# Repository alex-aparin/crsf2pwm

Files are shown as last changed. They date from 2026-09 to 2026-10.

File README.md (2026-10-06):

# crsf2pwm




CRSF-to-PWM converter for an RC car: receives CRSF from an ExpressLRS or
Crossfire receiver over UART and outputs two servo PWM signals, one for the
steering servo and one for the motor ESC. Plain synthesisable
SystemVerilog, one clock, no vendor primitives. The current target is a
Cyclone IV E development board; a MAX II EPM240 revision exists but the
design is a few logic cells too big for it.

## Layout

```
rtl/          synthesizable code, the only thing that goes into Quartus
tb/           testbenches for Icarus Verilog, one per module plus tb_top
tb/lib/       helpers shared by the testbenches (CRC, frame building)
tb/model/     Python reference model and the test vector generator
tb/vectors/   generated vectors, committed, `make vectors` regenerates them
sim/          Makefile for running simulations, waveforms land here
quartus/      Quartus project: .qpf, one .qsf per revision, .sdc, the clock probe
tools/        build, JTAG check, program, udev rule for the USB Blaster
hw/           KiCad board project
docs/         notes: design, CRSF protocol, servo PWM, pinout, board bring-up
```

## Design

```
rx -> 2 FF sync -> uart_rx -> crsf_parser -> steer_val ----------> pwm_chan -> steer
                                          -> thr_val -> failsafe mux -> pwm_chan -> throttle
                                          -> frame_valid -> link watchdog
                              pwm_timebase -> tick, start, head -> both channels, watchdog
```

`docs/design.md` has the module contracts, the timing, the failsafe policy,
the LE budget and the reasoning behind the choices. `docs/crsf.md` and
`docs/servo_pwm.md` cover the two protocols.

## Tools (Linux)

Simulation and lint from the distribution:

```
sudo apt install iverilog gtkwave make python3 verilator
```

Quartus Prime Lite for synthesis and programming: the small installer from
altera.com (`qinst-lite-linux-<version>.run`, free, needs an account),
components Quartus Prime plus the Cyclone IV device support, and MAX II if
the CPLD revision matters; Questa is not needed. It lands in
`~/altera_lite/<version>/quartus`, which is not on PATH: the scripts in
`tools/` find it by themselves, and `. tools/quartus-env.sh` puts it on
PATH for a shell. The USB Blaster needs `tools/udev-install.sh` once.

Verified with Icarus 11, Verilator 5.052, Quartus Prime Lite 25.1std on
Ubuntu 22.04.

## Simulation

Without make, from the `sim` directory:

```
mkdir build
iverilog -g2012 -Wall -I ../tb/lib -s tb_top -o build/tb_top.vvp ../tb/tb_top.sv ../rtl/*.sv
vvp -N build/tb_top.vvp
gtkwave build/tb_top.vcd
```

With make:

```
cd sim
make                 all testbenches
make tb_top          one testbench
make pwm_out         same as make tb_pwm_out
make waves-tb_top    open waveforms in GTKWave
make lint            Verilator lint, if installed
make vectors         regenerate tb/vectors from the Python model
```

Every testbench is self-checking: it prints `PASS` and exits 0, or prints the
failing checks and exits 1 through `$stop`, so `make` fails and the VS Code
task turns red. A watchdog ends a hung run.

`make waves-tb_top` also loads `sim/tb_top.gtkw` if it exists. Save one from
GTKWave with File > Write Save File to keep the signal layout between runs.

## Continuous integration

`.github/workflows/sim.yml` runs on every push and pull request: all
testbenches in Icarus (`make -C sim -k all`), the Python model self-test with
a check that the committed `tb/vectors/` match the generator, and Verilator
lint of the RTL with `-Wall`. The waveforms of a failed run are attached to
the run as an artifact for a week. The badge above shows the state of `main`.

`.github/workflows/hw.yml` runs on changes under `hw/`: ERC of the schematic
and DRC of the board with kicad-cli 10.0 (through `actions-for-kicad/kicad-actions`),
plus a PDF of the schematic and of the board layers. Reports and PDFs are
attached to the run as the `board` artifact for 30 days. ERC tolerates only
"Pin not connected" on the unused U1 pins, which have no no-connect flags yet.

## VS Code

`.vscode/` has tasks and recommended extensions. Open a testbench or a module
file and press Ctrl+Shift+B: the testbench for that file runs in `sim/`, so
`rtl/pwm_out.sv` and `tb/tb_pwm_out.sv` both run `tb_pwm_out`. Errors from
Icarus appear in the Problems panel. Other tasks under Terminal > Run Task:
waves in GTKWave, run + waves, all testbenches, lint, clean.

The Verilog-HDL extension lints the open file with Icarus on save. The Surfer
extension opens a `.vcd` from `sim/build/` inside VS Code as an alternative
to GTKWave.

## Build and program

The Quartus project `quartus/crsf2pwm.qpf` has three revisions:

| Revision | Target | Output |
|---|---|---|
| `crsf2pwm_c4` | the Saylinx Cyclone IV board, EP4CE6F17C8N | `.sof`, and `.jic` for the flash |
| `clock_probe` | the same board, bring-up helper: oscillator to LEDs and header pins | `.sof` |
| `crsf2pwm` | MAX II EPM240 | `.pof`; 234 of 240 LEs with the area settings in the `.qsf`, see `docs/design.md` |

Everything goes through the scripts in `tools/`, which find Quartus, check
the cable and print the numbers that matter:

```
tools/udev-install.sh            once: let Quartus open the USB Blaster
tools/jtag-check.sh              cable found? board answering?
tools/build.sh [revision]        compile, default crsf2pwm_c4; errors, warnings by code, LEs, slack
tools/program.sh [revision]      into the FPGA over JTAG, gone at power-off
tools/program.sh --flash         into the configuration flash, loads at every power-up
tools/crsf_send.py [options]     play a receiver: CRSF frames from the PC over the board's USB-UART (pyserial)
```

The step-by-step procedure with what to expect at each step, from the
first `jtagconfig` to the car, is `docs/bringup.md`. The GUI works too:
open the `.qpf`, pick the revision under Project > Revisions, Start
Compilation, Programmer.

Current state: the Cyclone IV revision compiles clean in Quartus Prime
Lite 25.1 (273 LEs, Fmax well above 50 MHz) with the pins from
`docs/pinout.md`. Not yet confirmed on the board.

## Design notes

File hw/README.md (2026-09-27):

# Board

KiCad project: `crsf2pwm-board.kicad_pro`, `.kicad_sch`, `.kicad_pcb`.

- `lib/` project symbols, footprints and 3D models, paths via `${KIPRJMOD}`.
- `fab/` gerbers, BOM and position file, committed at the moment of ordering boards.
- Net names as in `docs/pinout.md`.

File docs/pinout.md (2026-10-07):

# Pinout

Net names in KiCad match the ports of `crsf2pwm_top`. When changing a
pin, update three places: this table, the revision's `.qsf`
(`quartus/crsf2pwm_c4.qsf` for Cyclone IV, `quartus/crsf2pwm.qsf` for
MAX II), and the schematic.

Four pins in total. `clk` must sit on a dedicated clock input: GCLK0..3
(pins 12, 14, 62, 64) on the EPM240T100, CLK0..CLK15 on the Cyclone IV E;
the fitter warns when a clock is placed elsewhere. The other three go on
any user I/O that reaches a header and is not shared with an on-board LED,
button or memory.

Cyclone IV board: Saylinx, EP4CE6F17C8N (256-pin BGA, pins named like
E1), a clone of the ALINX AX4010. The basics-graphics-music project
(github.com/yuri-panchul/basics-graphics-music) has this exact board as
`boards/saylinx`: its `board_specific.qsf` lists every pin and matches the
silkscreen here, and `board_specific_top.sv` shows the polarities: keys
are active low, LEDs light on 1, 7-segment segments and digits are active
low.

| Net | Module port | Cyclone IV pin | EPM240 pin | Board connector | Notes |
|---|---|---|---|---|---|
| CLK50 | clk | E1 | 64 (GCLK3) | on-board oscillator | 50 MHz, dedicated clock input |
| CRSF_RX | rx | M2 | 54 + 55 | on-board USB-UART bridge, PC -> FPGA | frames from a PC over the board's mini-USB; for a receiver switch to T14 (right header pin 3, GND pin 1), 3.3 V, idle high, receiver RX pin left open |
| STEER | steer | T13 | 49 + 50 | right header pin 5 | servo powered separately, 220 ohm .. 1 k series resistor |
| THROTTLE | throttle | T12 | 51 + 52 | right header pin 7 | ESC powered separately, same resistor |
| LED0..3 | led[0..3] | D9, C9, F9, E10 | | on-board LEDs, light on 1 | status: link, frames, first frame, rx activity |

On the EPM240 each signal takes a pair of adjacent package pins. The port
sits on the first pin of the pair; the second is reserved in the `.qsf` as
a tri-stated input (`RESERVE_PIN`) and both pads are joined on the board,
so the pad is twice as wide and a solder bridge inside the pair changes
nothing. Pins 53, 56 and 57 stay free as spacers. In the same spirit pin 58
is tied to VCCIO2 (pin 59) and pin 61 to GNDIO (pin 60), both reserved as
tri-stated inputs: the one state that is safe against either rail, whatever
the global unused-pin setting becomes. The pairs straddle the I/O bank
boundary (51 is bank 1, 52 bank 2); both banks run at 3.3 V.

Other board resources, from the AX4010 data, for later: keys M15, M16,
E16 and reset N13 (with pull-ups); the on-board USB-UART bridge connects
to the FPGA on M2 (FPGA receives) and N1 (FPGA transmits), an option for
feeding test frames from the PC without a separate adapter.

## Saylinx board headers

Transcribed from the silkscreen on the bottom side; the labels are FPGA
pin names. "Left" and "right" are as seen from the bottom, with the VGA
connector at the top.

Left header, numbering starts at the top row, `[2] [1]`: even pins in the
left column, odd in the right.

| Pins | Left | Right |
|---|---|---|
| 2, 1 | VCC | GND |
| 4, 3 | J16 | B1 |
| 6, 5 | A2 | B3 |
| 8, 7 | A3 | B4 |
| 10, 9 | A4 | B5 |
| 12, 11 | A5 | B6 |
| 14, 13 | A6 | B7 |
| 16, 15 | A7 | B8 |
| 18, 17 | A8 | B9 |
| 20, 19 | A9 | B10 |
| 22, 21 | A10 | B11 |
| 24, 23 | A11 | B12 |
| 26, 25 | A12 | B13 |
| 28, 27 | A13 | D5 |
| 30, 29 | D6 | C6 |
| 32, 31 | E7 | F8 |
| 34, 33 | C8 | D8 |
| 36, 35 | E8 | E9 |
| 38, 37 | GND | GND |
| 40, 39 | 3V3 | 3V3 |

Right header, numbering starts at the bottom row, `[1] [2]`: odd pins in
the left column, even in the right, counting upwards.

| Pins | Left | Right |
|---|---|---|
| 39, 40 | 3V3 | 3V3 |
| 37, 38 | GND | GND |
| 35, 36 | P1 | N2 |
| 33, 34 | R1 | P2 |
| 31, 32 | K9 | P8 |
| 29, 30 | L10 | L9 |
| 27, 28 | T2 | M9 |
| 25, 26 | T3 | P3 |
| 23, 24 | T4 | R3 |
| 21, 22 | T5 | R4 |
| 19, 20 | T6 | R5 |
| 17, 18 | T7 | R6 |
| 15, 16 | T8 | R7 |
| 13, 14 | T9 | R8 |
| 11, 12 | T10 | R9 |
| 9, 10 | T11 | R10 |
| 7, 8 | T12 | R11 |
| 5, 6 | T13 | R12 |
| 3, 4 | T14 | R13 |
| 1, 2 | GND | VCC |

VCC on the headers is the board's 5 V input rail, 3V3 is the regulated
3.3 V. In the AX4010 data these two headers are GPIO_0 and GPIO_1, plain
I/O not shared with any on-board peripheral.

## clock_probe

`quartus/clock_probe.qsf` builds `quartus/probe/clock_probe.sv`: a
26-bit counter on `clk` = E1. The four LEDs count in binary at 0.75 Hz,
the first sign of life without any instrument, and four divided outputs
sit on each header for the scope. At 50 MHz:

| Header pin | FPGA pin | Signal | Period |
|---|---|---|---|
| right 3, left 6 | T14, A2 | clk / 2^26 | 1.34 s |
| right 5, left 8 | T13, A3 | clk / 2^23 | 168 ms |
| right 7, left 10 | T12, A4 | clk / 2^16 | 1.31 ms |
| right 9, left 12 | T11, A5 | clk / 2^6 | 1.28 us |

Nothing toggling means E1 is not the oscillator pin; doubled periods mean
a 25 MHz oscillator.

## JTAG, 2x5 header for USB Blaster

| Pin | Signal |
|---|---|
| 1 | TCK |
| 2 | GND |
| 3 | TDO |
| 4 | VCC 3.3 V, powers the cable buffers |
| 5 | TMS |
| 6 | not connected |
| 7 | not connected |
| 8 | not connected |
| 9 | TDI |
| 10 | GND |

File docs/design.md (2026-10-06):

# Design notes

What each module promises, how the pieces fit, and why they look the way
they do. Numbers are for 50 MHz and 420 kbaud unless said otherwise.

## Block diagram

```
          +------+    +---------+    +-------------+  steer_val   +----------+
rx ------>| sync |--->| uart_rx |--->| crsf_parser |------------->| pwm_chan |---> steer
          | 2 FF |    |         |    |             |  thr_val     +----------+
          +------+    +---------+    |             |----+  +--+   +----------+
                       data, valid   |             |    +->|mux|-->| pwm_chan |---> throttle
                                     +-------------+       +--+   +----------+
                                        frame_valid |         ^ THROTTLE_FAILSAFE
                                                    v         |
                                     +---------------+  link_ok, ever_valid
                                     | link watchdog |<------------------+
                                     +---------------+                   |
                                            ^ start                      |
                                     +--------------+  tick, start, head |
                                     | pwm_timebase |--------------------+--> both channels
                                     +--------------+
```

One clock, 50 MHz, everywhere. No derived clocks: the 1.6 MHz tick is a
one-clock enable. No reset: every register has a power-up value and the
all-zero state is the safe one (no pulses).

## Modules

| Module | Job | Contract |
|---|---|---|
| `uart_rx` | 8N1 bytes from a synchronised rx | `valid` is a one-clock strobe, `data` holds the byte in that clock. `frame_err` strobes instead of `valid` when the stop bit is low; a break gives one error. |
| `crc8` | CRC-8/DVB-S2, byte-parallel | `clear` then `valid` per byte; `crc` is the CRC of everything fed since `clear`, available in the clock after the last byte. |
| `crsf_parser` | frames in, two channels out | `frame_valid` strobes once per RC frame with a good CRC; `ch_a`, `ch_b` change only in that clock. Everything else is consumed and ignored. Silence of 100 us inside a frame aborts it. |
| `pwm_timebase` | 0.625 us tick, 20 ms period | `tick` one-clock enable at 1.6 MHz average; `start` the last clock of a period; `head` high for the first 1408 ticks of a period. |
| `pwm_chan` | one servo pulse | Samples `value` and `enable` on `start`. Width = 1408 + value ticks, exact. `enable` = 0 stops pulses from the next period on. |
| `pwm_out` | timebase + one channel | The standalone single-output module; `tb_pwm_out` tests it. |
| `crsf2pwm_top` | the car | Wires the above, adds the synchroniser, the link watchdog and the throttle failsafe mux. |

## Timing

**UART.** 119 clocks per bit. The start bit is detected by level and
confirmed half a bit later; data bits are sampled every 119 clocks after
that, i.e. at 0.5, 1.5 .. 8.5 bit periods, the stop bit at 9.5. A baud
rate error e moves the last sample by 9.5 e; +-3 % is 0.29 bit, the window
is +-0.5. `valid` comes 9.5 bit periods after the start edge.

**Parser.** One state step per byte. The CRC register is cleared by the
length byte, fed by the type and payload bytes, and compared with the CRC
byte in the clock it arrives; `frame_valid` is registered, so it strobes
one clock after the CRC byte's `valid`. Payload byte b is on the bus when
the down counter `remaining` equals 23 - b; the channel bit map is built
from that at elaboration time, so extraction is enables on the shadow
registers, no shifting.

**Timebase.** 50 MHz / 1.6 MHz = 31.25 clocks per tick; the accumulator
adds 8 modulo 250, ticks come 32, 31, 31, 31 clocks apart and every 125
clocks hold exactly 4. Period = 32000 ticks = 1 000 000 clocks = 20 ms.

**Channel.** Both edges of `pwm` are two clocks after the tick that causes
them, so the width is exact to the tick and the jitter is one clock. The
first pulse after `enable` rises is a full pulse; the last one after it
falls completes.

**Latency, frame to output.** The frame takes 0.62 ms on the wire, the
parser has the channels at its last byte, and the channel picks them up
at the next `start`: 0.6 to 20.6 ms, average about 10 ms. At 50 Hz that is
inherent; a faster PWM rate would only help if the servo accepted it.

## Failsafe policy

| State | steer | throttle |
|---|---|---|
| Power-up, no frame yet | no pulses | no pulses |
| Link up | channel | channel |
| No good RC frame for `FAILSAFE_PERIODS` periods (25 = 0.48..0.50 s) | no pulses, servo goes limp | pulses at `THROTTLE_FAILSAFE`: 992 = 1500 us, stop for a reversible car ESC |
| Frames again | channel from the next period | channel from the next period |

Why no pulses at power-up: an ESC arms only after it has seen a safe
throttle, and with no signal it just waits; nothing moves while the
transmitter is off. ELRS PWM receivers do the same. Why throttle keeps
pulsing in failsafe: silence would make a car ESC coast or beep, a defined
neutral pulse stops it. For a one-way (multirotor style) ESC set
`THROTTLE_FAILSAFE` to 172, its zero throttle. Check which ESC is on the
car before the first drive.

The watchdog counts `start` strobes since the last `frame_valid`: a 5-bit
counter instead of a 25-bit one at 50 MHz. Bad frames do not feed it, so a
receiver that keeps sending garbage still trips it.

## Resources

Measured with Quartus Prime Lite 25.1std, default settings, no pins
assigned. Logic cells after synthesis per module (own cells in
parentheses), then what the fitter needed.

| Module | Cyclone IV E, LCs | MAX II, LCs |
|---|---|---|
| `crsf_parser` incl. `crc8` | 99 (78) | 134 (110) |
| `crc8` | 21 | 24 |
| `pwm_timebase` | 47 | 56 |
| `pwm_chan` steer | 17 | 18 |
| `pwm_chan` throttle, absorbs the failsafe mux | 28 | 28 |
| `uart_rx` | 32 | 38 |
| top glue: sync, watchdog | 12 | 12 |
| **Synthesis total** | **235** | **286** |
| **Fitter** | **264 of 6272, 160 registers** | **266 with the default settings: does not fit. 234 of 240 with the area settings in the .qsf, 162 registers** |

Cyclone IV: 4 % of an EP4CE6, Fmax 132 MHz against the 50 MHz required,
worst setup slack 12 ns. That is the target board now.

MAX II: the estimate of 220 was 20 % optimistic, mostly in the parser
(110 own cells against 80 guessed: the byte-position decodes and the
enable muxes on 44 shadow/output bits cost more than one LE per bit) and
the timebase (56 against 40: two 15-bit compares plus the accumulator).
With the defaults the EPM240 is 26 cells short. What makes it fit is the
fitter packing unrelated LUTs and registers into one LE:
`AUTO_PACKED_REGISTERS_MAXII "MINIMIZE AREA WITH CHAINS"` takes 266 to
238, `OPTIMIZATION_TECHNIQUE AREA` plus `STATE_MACHINE_PROCESSING
"MINIMAL BITS"` to 234, worst setup slack 5.1 ns. That is 98 %: nothing
more goes in without giving something back. What the RTL could give back,
measured 2026-10-06 in scratch copies with those settings, fitted cells:

| Change | LEs | Contract |
|---|---|---|
| as is | 234 | |
| timebase tick from a 5-bit sub counter plus a 2-bit phase instead of the add-8-modulo-250 accumulator, same 32/31/31/31 pattern | 227 | unchanged |
| parser silence timeout counted in timebase ticks: 8-bit gap counter instead of 13, `tick` input on the parser | 228 | unchanged, `GAP_US` stays |
| both of the above | 221 | unchanged |
| plus a 32768-tick period, 20.48 ms: the counter wraps by itself, `start` from the carry out, `head` = `cnt < 1408` combinational | 211 | period 20.48 ms, the testbenches expect 20 ms |

A combinational `head` on its own saves nothing once registers are packed.
Not measured: dropping the parser's output registers and letting the
channels sample the shadows gated by a "frame complete and good" flag,
22 registers, but the `ch_a`/`ch_b` contract changes and a channel may
skip a period.

Decisions already taken with the budget in mind, and still worth keeping
on Cyclone IV because they cost nothing: one timebase shared by both
channels, a down counter per channel instead of latch plus comparator,
`uart_rx` exposing its shift register as `data`, a watchdog that counts
periods rather than clocks.

## Verification

Every testbench is self-checking, prints `PASS` or the failing checks, and
exits through `$finish` or `$stop` so that `vvp -N` returns 0 or 1.
Testbenches read on `negedge clk`, drive UART lines in nanoseconds, and
carry a watchdog against hangs.

| Testbench | Proves | Notes |
|---|---|---|
| `tb_crc8` | CRC against 1000 vectors from the Python model plus the catalogue value 0xBC, clear mid-stream, gaps, back-to-back bytes | vectors in `tb/vectors/`, `make vectors` regenerates |
| `tb_uart_rx` | single bytes, back-to-back, +-3 % baud, glitch rejected, framing error, break, one-clock strobes, strobe count equals bytes sent | |
| `tb_crsf_parser` | two parsers on one stream (channels 0/1 and 3/15): good frames, extremes 0 and 2047, bad CRC, foreign types and lengths, garbage, bogus lengths, doubled sync, header-only, truncated frames with and without a gap, back-to-back frames, wire-speed spacing, foreign address; outputs change only in the strobe clock | |
| `tb_pwm_out` | widths for 172/992/1811/0/2047 within +-1 us, period 20 ms, value change mid-pulse, no retrigger, enable drop mid-pulse, silence while disabled | about 40 s |
| `tb_top` | bytes on rx to pulse widths; power-up silence, link up, value changes, bad and foreign frames between good ones, failsafe not premature, failsafe reached, throttle neutral in failsafe, recovery | `FAILSAFE_PERIODS` = 3 to keep it short; about 1.5 min |

The same suite runs in GitHub Actions on every push
(`.github/workflows/sim.yml`), together with the Python model self-test, a
check that the committed vectors match the generator, and Verilator lint.
`make lint` with `-Wall` is clean under Verilator 5.052 for both
`crsf2pwm_top` and `pwm_out`.

Synthesis: both Quartus revisions compile with 0 errors; the Cyclone IV
revision fits and meets timing, the MAX II one does not fit (see
Resources). Not verified yet: the design on a board.

## Decisions worth remembering

- **Level-triggered start detection with a half-bit confirmation** rather
  than an edge detector: one register less, and the confirmation is what
  rejects glitches anyway.
- **`S_WAIT` after a framing error**: without it a break condition, which
  is what an unplugged receiver looks like, would produce a byte and an
  error every ten bit periods.
- **Byte-parallel CRC**: the loop in a function unrolls to XORs. The
  bit-serial variant the roadmap mentions would save a few LEs at the cost
  of a counter and an interlock; not worth it while the budget holds.
- **Silence timeout in the parser** is what makes a frame that stops short
  cost nothing. A truncated frame glued to the next one with no gap still
  loses that next frame to the CRC check (`tb_crsf_parser` case 8); no
  byte-level parser can tell those apart, and receivers do leave gaps.
- **`frame_valid` only for RC frames**: the watchdog then measures exactly
  what matters, "do we have fresh stick data", and link statistics frames
  cannot keep a dead link alive.
- **Shadows plus output registers in the parser** are the price of the
  atomic-update contract: a bad frame never shows, the channels are never
  half old and half new.
- **Sized constants through casts.** `localparam logic [W-1:0] X = W'(expr)`
  is the one form that Icarus 11 accepts, Verilator lints clean and Quartus
  does not truncate silently. Plain `= expr` draws WIDTHTRUNC from
  Verilator, a plain `int` constant draws WIDTHEXPAND at every use.
- **Verilator's PROCASSINIT is switched off** in `make lint`: it objects to
  registers initialised in their declaration and written in `always_ff`,
  which is exactly the no-reset style chosen here.
- **Icarus 11 quirks met on the way**, so nobody trips again: no `'{}`
  array literals in declarations, `before` is a keyword, an initialiser on
  a variable declared inside a `begin` block runs once at time 0, empty
  `()` task ports draw a warning, and `$readmemh` warns when the array is
  larger than the file, hence the generated `crc8_size.svh`.

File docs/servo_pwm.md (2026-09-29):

# Servo PWM: what the outputs must produce

## The signal

The command is the width of one positive pulse, repeated every frame. The
line idles low.

```
value 172:   _|‾‾|______________________________|‾‾|_______   988 us high
value 1811:  _|‾‾‾‾|____________________________|‾‾‾‾|_____   2012 us high
              <-------------- 20 ms -------------->
```

| Pulse width | Meaning | CRSF |
|---|---|---|
| 988 us | one end of travel | 172 |
| 1500 us | centre, neutral | 992 |
| 2012 us | other end of travel | 1811 |

Period 20 ms, 50 Hz. This is not duty-cycle PWM: the servo starts a timer
on the rising edge and measures how long the line stays high. A 1500 us
pulse means centre whether it repeats every 20 ms or every 10 ms; the
duty cycle changes from 7.5 % to 15 %, the position does not. Anything
from roughly 3 ms to 25 ms of period works, digital servos and ESCs accept
333..500 Hz, and 50 Hz is what every servo accepts.

The useful information sits in a 1 ms window around 1.5 ms. Pulses of
0 us or 20 ms are not "minimum" and "maximum", they are the absence of a
signal.

## Where the numbers come from

Analogue servos of the 1970s compare the input pulse with a 1..2 ms
one-shot driven by the feedback potentiometer, which fixed the 1..2 ms
window and 1.5 ms centre. The 20 ms frame comes from PPM: up to eight
channels of up to 2 ms each plus a sync gap. The 988 and 2012 endpoints
are the OpenTX convention of 100 % = 512 us, see docs/crsf.md.

## What matters and what does not

- Width accuracy: +-1 us is plenty, a servo resolves about 1..2 us.
- Pulse-to-pulse stability at a constant value: the servo takes jitter as
  commands and buzzes.
- Exactly one rising edge per period. A second pulse inside a period is
  read as a second frame with a nonsense width.
- The period itself is not critical, 20.0 or 19.7 ms makes no difference.

## Outside the window

- No pulses, line low: the servo goes limp and can be turned by hand, the
  ESC sees signal loss. Acceptable failsafe for steering.
- Line constantly high: no edges, no signal.
- Below about 900 us or above about 2100 us: most servos still follow and
  may hit the mechanical stop and overheat. ESCs treat it as minimum or
  maximum or as invalid.
- CRSF 0..2047 through pwm_out gives 880..2159 us. ELRS PWM receivers have
  an "extended" 885..2115 us mode, so passing such values through is
  accepted practice.

## ESC

- Multirotor BLHeli_S / BLHeli_32 with default settings: 988..1000 us is
  zero throttle (armed, motor stopped), 2012 us full throttle, no reverse.
  The ESC arms only after it has seen low throttle at power-up.
- Car ESC, or BLHeli in bidirectional 3D mode: 1500 us is stop, below is
  reverse or brake, above is forward. Needs neutral at power-up.
- Therefore the throttle failsafe is a defined pulse, never silence: 1500
  us for a reversible ESC, 988 us for a one-way one. Check which kind is
  on the car before the integration stage.

## Reference device: ELRS PWM receiver

Does the same job as this project. Defaults: 50 Hz, 988..2012 us, centre
1500. Output modes 50, 60, 100, 160, 333, 400 Hz. Failsafe per channel,
988..2012 us, default 1500 except output 3 (throttle) at 988. No pulses
until the first connection so the ESC can calibrate. Failsafe after 1 s
without a valid packet or at link quality 0.
https://www.expresslrs.org/hardware/pwm-receivers/

## How the outputs are made

Two modules, see docs/design.md for the reasoning.

`pwm_timebase`, one per design:

- Tick of 0.625 us, one CRSF unit, from a fractional divider: at 50 MHz
  an accumulator adds 8 every clock modulo 250, a tick on every wrap,
  50 MHz * 8 / 250 = 1.6 MHz. Ticks are 32, 31, 31, 31 clocks apart.
- Period counter 0..31999 in ticks, 15 bits.
- `start`: the last clock of a period. `head`: high for the first 1408
  ticks of every period, the 880 us that every pulse contains.

`pwm_chan`, one per output:

- On `start` it loads `value` into an 11-bit down counter and latches
  `enable`. The comparator and the width latch of the textbook design are
  replaced by this counter: no adder, no 15-bit compare.
- The pulse is high while `head` or while the counter is not zero; the
  counter runs only after `head` ends. Width = 1408 + value ticks exactly.
- Because value and enable are sampled once per period, a new CRSF frame
  mid-period never tears or retriggers a pulse, and enable = 0 stops the
  pulses from the next period on.

`pwm_out` is the two together for a single output; it is what
`tb_pwm_out` tests.

## Testbench checklist for tb_pwm_out

- Values 172, 992, 1811: widths 987.5, 1500, 2011.875 us, tolerance +-1 us.
- Values 0 and 2047: 880 and 2159.375 us, no overflow.
- Period 20 ms between two rising edges.
- value changed mid-pulse: the current pulse keeps its old width, the
  next one has the new width.
- enable dropped mid-pulse: the current pulse completes, no next pulse.
- Dump only the top level, `$dumpvars(1, ...)`: a period is a million
  clocks and the counter changes every one of them.

## References

- Wikipedia, Servo control: https://en.wikipedia.org/wiki/Servo_control
- BLHeli manuals: https://github.com/bitdump/BLHeli
- Servo datasheets with the pulse spec: Tower Pro SG90 / MG996R (one page,
  widely mirrored); Futaba, Hitec and Savox list "pulse width range" and
  "neutral" per model on their sites.

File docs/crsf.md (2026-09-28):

# CRSF: what the decoder needs to know

## Physical layer

- UART 8N1, 420000 baud by default for ELRS and Crossfire.
- 3.3 V levels. Only the receiver's TX line is needed; telemetry is optional.
- ELRS sends an RC frame at the link packet rate, e.g. every 2 ms at 500 Hz.
  A 26-byte frame takes about 0.62 ms.

## Frame

| Byte | Value | Meaning |
|---|---|---|
| 0 | 0xC8 | destination address, flight controller |
| 1 | length | number of bytes after this field: type + payload + CRC |
| 2 | type | 0x16 for RC channels, 0x14 for link statistics |
| 3.. | payload | exactly 22 bytes for type 0x16 |
| last | CRC8 | over the type byte and the payload |

For the RC frame the length is always 0x18 (24). Other frames have length up to 62.

## CRC

CRC-8/DVB-S2: polynomial 0xD5, initial value 0x00, no reflection, no final XOR.

```
crc ^= byte;
for (i = 0; i < 8; i++)
    crc = (crc & 0x80) ? (crc << 1) ^ 0xD5 : (crc << 1);
```

## Channel packing

16 channels of 11 bits back to back, LSB first, starting at bit 0 of byte 0.
Channel 0 is byte0[7:0] plus byte1[2:0]. Channel 1 is byte1[7:3] plus byte2[5:0].

Since UART also delivers bits LSB first, the serial bit stream of the payload
is simply channel 0, channel 1, channel 2 and so on. A bit counter modulo 11
and a channel counter are enough to pick out a channel without buffering.

## Channel values

Each channel is an 11-bit field, so 0..2047 fits physically. The
specification defines 0..1984 as the valid range, centre 992. Full stick
travel at the usual +-100 % limits is 172..1811.

| Stick | Transmitter units | Pulse | CRSF |
|---|---|---|---|
| -100 % | -1024 | 988 us | 172 |
| 0 | 0 | 1500 us | 992 |
| +100 % | +1024 | 2012 us | 1811 |
| -150 % | -1536 | 880 us after clamping | 0 |
| +150 % | +1536 | 2120 us after clamping | 1984 |

Formula from the specification: us = (value - 992) * 5 / 8 + 1500.
Betaflight fits the same line as 0.62477 * value + 881.

Where the numbers come from:

- EdgeTX and OpenTX hold a channel as -1024..+1024 for -100..+100 %.
- Their PPM output maps that to 1500 +- 512 us. Hence 988 and 2012 instead
  of 1000 and 2000: 512 is a power of two, convenient on 8-bit radios.
- Futaba SBUS encodes microseconds in 5/8 us steps with 992 at 1500 us,
  and CRSF took the SBUS encoding so flight controllers could reuse the
  conversion. Transmitter units to CRSF units is 0.5 us / 0.625 us = 4/5:
  crsf = 992 + channel * 4 / 5, clamped to 0..1984 (EdgeTX crossfire.cpp).
  +-1024 * 4 / 5 = +-819, so 992 +- 819 = 172..1811.

So 172..1811 is a convention for where +-100 % sits, not a property of
the protocol. With extended limits on the transmitter values outside it
do arrive. The parser passes the 11 bits through unchanged, and pwm_out
handles any 0..2047 without overflow: it produces 880..2159 us, which
servos and ESCs accept as slightly extended travel.

ELRS sends switch channels with reduced resolution. On the receiver a
two-position switch reads 191 or 1792 (1000 or 2000 us) and a
three-position switch adds 992. Sticks use the full range.

One CRSF unit is exactly 5/8 us = 0.625 us. Counting time in 0.625 us
ticks (1.6 MHz) turns the conversion into an addition: width in ticks =
value + 1408, period 20 ms = 32000 ticks. This is how pwm_out works.

## Failsafe

On link loss ELRS by default stops sending RC frames. The decoder must
watch the gap itself. Two references for the numbers:

- This project: no valid frame for about 0.5 s, timeout is a parameter.
- ELRS PWM receivers: 1 s without a valid packet or link quality 0. The
  failsafe action is a configurable pulse width per channel, default
  1500 us on all outputs except the throttle output, which defaults to
  988 us. Before the first connection they output no pulses at all so the
  ESC can be calibrated.

What to output on failsafe depends on the load, see docs/servo_pwm.md:
the steering servo can simply get no pulses, the ESC needs a defined
pulse, neutral for a reversible ESC or minimum for a one-way one.

## References

- CRSF working group specification: https://github.com/crsf-wg/crsf/wiki
- RC channels frame, value range and the 5/8 formula:
  https://github.com/crsf-wg/crsf/wiki/CRSF_FRAMETYPE_RC_CHANNELS_PACKED
- Betaflight conversion, `crsfReadRawRC` in `src/main/rx/crsf.c` and
  `sbusChannelsReadRawRC` in `src/main/rx/sbus_channels.c`:
  https://github.com/betaflight/betaflight
- EdgeTX transmitter side, `radio/src/pulses/crossfire.cpp`:
  https://github.com/EdgeTX/edgetx
- ExpressLRS documentation: https://www.expresslrs.org/
- ExpressLRS PWM receivers, a finished device doing the same job:
  https://www.expresslrs.org/hardware/pwm-receivers/

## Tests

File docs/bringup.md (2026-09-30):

# Board bring-up

Getting the design from a green simulation onto the Saylinx Cyclone IV
board and to a moving car, one observable step at a time. Linux only; the
scripts live in `tools/`. Pins are in docs/pinout.md.

## What you need

- The board, powered through its mini-USB from a computer port or a 5 V
  supply, power switch ON, power LED lit. The USB Blaster does not power
  the board; it takes 3.3 V from the board's JTAG header to drive its
  buffers.
- USB Blaster or a clone in the header marked JTAG, top centre next to the
  CAMERA header. The other 2x5 header near the USB jack is not JTAG.
- Quartus Prime Lite with the Cyclone IV device support, see README.
- An oscilloscope for the pulse widths. A multimeter helps with the
  wiring.
- Later: an ELRS receiver bound to a transmitter, a servo, the ESC.

## 1. Cable and chain

```
tools/udev-install.sh        # once per machine, then replug the Blaster
tools/jtag-check.sh
```

| `jtagconfig` says | Meaning | Do |
|---|---|---|
| `No JTAG hardware available` | Linux does not let Quartus open the cable | udev rule, replug, another USB port |
| `USB-Blaster` then `Unable to read device chain - JTAG chain broken` | cable fine, board silent (also `Error code 87` from `quartus_pgm`) | board power ON and LED lit; ribbon in the JTAG header, seated, key aligned; 3.3 V between header pins 4 and 2; ribbon continuity |
| `USB-Blaster` then `020F10DD EP4CE6(E22\|F17)/EP4CE10...` | the FPGA answers | go on |

The chain does not care whether the FPGA is configured, so a working
chain with a dead design is normal.

## 2. Clock probe

Before the real design, prove the oscillator pin and frequency:

```
tools/build.sh clock_probe
tools/program.sh clock_probe
```

Expected within a second of programming:

- The four LEDs count in binary: LED0 toggles about 6 times a second,
  LED3 once per 1.34 s.
- Scope on the right header (seen from the bottom, `[1][2]` at the bottom
  row): pin 7 = T12 gives a square wave of 1.31 ms period, pin 9 = T11 one
  of 1.28 us. Ground on pin 1.

| Observation | Meaning |
|---|---|
| LEDs count, 1.31 ms on T12 | 50 MHz on E1, as assumed |
| LEDs count twice as slowly, 2.62 ms | 25 MHz oscillator: set `CLK_HZ` to 25_000_000 in the top and rebuild |
| Nothing moves | E1 is not the oscillator pin, or the FPGA did not configure (Programmer reports success but check the CONF_DONE LED if the board has one) |

The probe stays until power-off; it is not written to the flash.

## 3. The design without a receiver

```
tools/build.sh
tools/program.sh
```

Right after programming all four LEDs are off and both outputs are low.
That is correct: no frame yet, no pulses, the ESC would not arm. The LEDs:

| LED | Lit when |
|---|---|
| LED0 | link up: good RC frames within the failsafe window |
| LED1 | blinking while frames arrive, about 4 Hz at 250 Hz packets |
| LED2 | at least one good frame since power-up |
| LED3 | glowing while bytes arrive on rx, valid or not |

In the current `crsf2pwm_c4.qsf` the CRSF input `rx` sits on M2, the
board's own USB-UART bridge. Plug the board's mini-USB into the PC (it
powers the board and shows up as `/dev/ttyUSB0`; the user must be in the
`dialout` group) and play the receiver with `tools/crsf_send.py`, which
builds the frames with `tb/model/crsf.py`. Needs pyserial:
`sudo apt install python3-serial`.

```
tools/crsf_send.py --steer 172 --throttle 1811   # fixed values: 987.5 us on pin 5, 2011.9 us on pin 7
tools/crsf_send.py --sweep 4                     # steer sweeps end to end every 4 s: watch the falling edge move
tools/crsf_send.py --interactive                 # a/d steer, w/s throttle, c centre, 1..9 presets, q quit
tools/crsf_send.py --bad-crc                     # every second frame spoiled: outputs must not twitch
tools/crsf_send.py --duration 3                  # stops after 3 s: LED0 off and steer silent half a second later
```

The bridge is a CH340; it cannot do exactly 420000 baud and lands about
1.5 % off, well inside the receiver's tested +-3 %. LED3 glows as soon as
the script runs, LED2 and LED0 follow with the first good frame, LED1
blinks.

## 4. Receiver

The receiver needs a header pin: in `crsf2pwm_c4.qsf` swap the two `rx`
lines so that `rx` is on T14 (the M2 line is left there commented out),
rebuild and reprogram. Then receiver TX to right header pin 3 (T14),
receiver GND to pin 1, receiver 5 V from pin 2 (the board's 5 V rail) or
from a separate 5 V supply; never 5 V onto a signal pin. Receiver RX stays
open. Receiver settings: protocol CRSF, not inverted, 420000 baud.

Transmitter on:

1. LED3 glows: bytes arrive. If it stays dark, the wire or the receiver's
   serial protocol setting.
2. LED2 and LED0 light, LED1 blinks: frames parse. LED3 on but LED2 off
   means bytes but no good frames: wrong baud rate, inverted signal (rx idle
   low on the scope), or another protocol.
3. Scope on pin 5 (steer) and pin 7 (throttle): pulses of 1 to 2 ms every
   20 ms, width following the sticks. Settings that work: 1 V/div, 10x
   probe with 10x set in the channel menu, 200 us/div, edge trigger on the
   channel, rising, level 1.5 V, mode Normal, trigger marker moved to the
   left. Measure > +Width reads the width, both outputs rise together so
   one trigger shows both.
4. Transmitter off: within half a second LED0 goes out, steer pulses stop,
   throttle keeps pulsing at 1500 us. Transmitter on again: everything
   resumes within a period.

## 5. Servo and ESC

- 220 ohm to 1 k in series with each signal wire, right at the board.
- Common ground between board, receiver, servo and ESC.
- Servo and ESC powered from the ESC's BEC, never from the board's 3.3 V.
  Check the BEC voltage: 6 V or 7.4 V BECs are common on car ESCs, the
  board's regulator survives them, most ELRS receivers do not.
- Which ESC: reversible car ESC or BLHeli in 3D mode stops at 1500 us,
  which is the default `THROTTLE_FAILSAFE` of 992; a one-way ESC wants
  `THROTTLE_FAILSAFE` = 172 (988 us). Set it in `crsf2pwm_c4.qsf` with
  `set_parameter -name THROTTLE_FAILSAFE 172` or change the default in
  the top and rebuild.
- First power-up with the transmitter off: nothing may move. Then
  transmitter on, throttle stick at neutral, the ESC arms.

## 6. Make it permanent

The `.sof` is gone at power-off. The configuration flash keeps it:

```
tools/program.sh --flash
```

This converts the `.sof` to a `.jic` for an EPCS4, the 4 Mbit flash the
Saylinx board answers with (silicon ID 0x12; the EP4CE6 image needs about
3 Mbit), and writes it through the FPGA. On another board the programmer
prints the ID it found in `Can't recognize silicon ID`: 0x10 EPCS1, 0x12
EPCS4, 0x14 EPCS16, 0x16 EPCS64, 0x18 EPCS128, W25Qxx parts report the
code of the EPCS of the same size. Then:

```
FLASH_DEVICE=EPCS16 tools/program.sh --flash
```

Power-cycle the board: it must come up with the LEDs dark and start
working as soon as the receiver talks.

## Troubleshooting summary

| Symptom | Look at |
|---|---|
| `quartus_pgm: command not found` | `. tools/quartus-env.sh` in this shell, or use the tools/ scripts, they source it |
| Board on mini-USB but no `/dev/ttyUSB0` | Ubuntu's `brltty` grabs every CH340 as a Braille display and detaches the driver a second after it appears (`dmesg` shows `claimed by ch341 while 'brltty'`): `sudo apt purge brltty`, replug |
| `Error code 87` / chain broken | section 1 |
| Probe LEDs dark | oscillator pin, section 2 |
| LED3 dark with receiver connected | rx wire, receiver protocol setting, receiver power |
| LED3 on, LED2 off | baud rate, inversion, protocol |
| Pulses present but the servo twitches | ground, series resistor, probe compensation before blaming the design |
| Servo fine, ESC does not arm | ESC type versus `THROTTLE_FAILSAFE`, arming sequence in the ESC manual |
| Works until power-off | section 6 |

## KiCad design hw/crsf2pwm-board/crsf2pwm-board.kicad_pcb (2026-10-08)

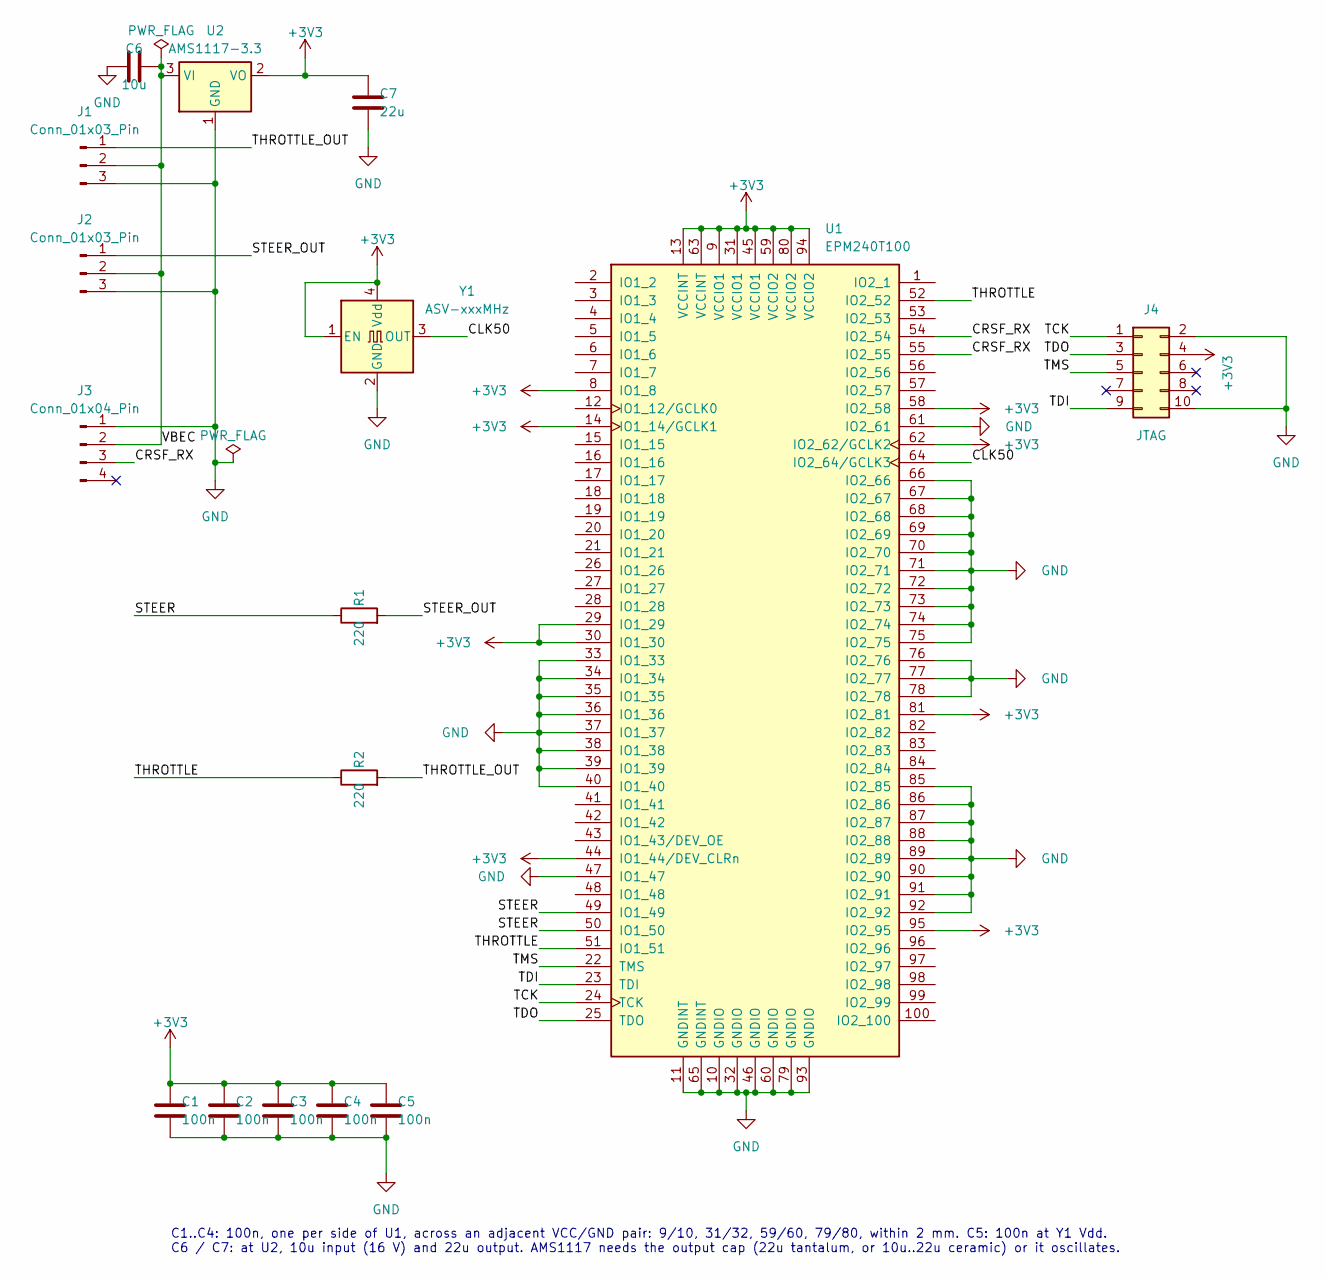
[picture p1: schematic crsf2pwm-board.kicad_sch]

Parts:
C1, C2, C3, C4, C5: 100n; C_1206_3216Metric_Pad1.33x1.80mm_HandSolder
C6: 10u; C_1206_3216Metric_Pad1.33x1.80mm_HandSolder
C7: 22u; C_1206_3216Metric_Pad1.33x1.80mm_HandSolder
J1, J2: Conn_01x03_Pin; PinHeader_1x03_P2.54mm_Vertical
J3: Conn_01x04_Pin; PinHeader_1x04_P2.54mm_Vertical
J4: JTAG; IDC-Header_2x05_P2.54mm_Vertical
R1, R2: 220; R_1206_3216Metric_Pad1.30x1.75mm_HandSolder
U1: EPM240T100; LQFP-100_14x14mm_P0.5mm
U2: AMS1117-3.3; SOT-223-3_TabPin2
Y1: ASV-xxxMHz; Oscillator_SMD_Abracon_ASV-4Pin_7.0x5.1mm

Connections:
+3V3: C1.1, C2.1, C3.1, C4.1, C5.1, C7.1, J4.4, U1.8 (IO1_8), U1.9 (VCCIO1), U1.13 (VCCINT), U1.14 (IO1_14/GCLK1), U1.29 (IO1_29), U1.30 (IO1_30), U1.31 (VCCIO1), U1.44 (IO1_44/DEV_CLRn), U1.45 (VCCIO1), U1.58 (IO2_58), U1.59 (VCCIO2), U1.62 (IO2_62/GCLK2), U1.63 (VCCINT), U1.80 (VCCIO2), U1.81 (IO2_81), U1.94 (VCCIO2), U1.95 (IO2_95), U2.2 (VO), Y1.1 (EN), Y1.4 (Vdd)
/CLK50: U1.64 (IO2_64/GCLK3), Y1.3 (OUT)
/CRSF_RX: J3.3, U1.54 (IO2_54), U1.55 (IO2_55)
/STEER: R1.1, U1.49 (IO1_49), U1.50 (IO1_50)
/STEER_OUT: J2.1, R1.2
/TCK: J4.1, U1.24 (TCK)
/TDI: J4.9, U1.23 (TDI)
/TDO: J4.3, U1.25 (TDO)
/THROTTLE: R2.1, U1.51 (IO1_51), U1.52 (IO2_52)
/THROTTLE_OUT: J1.1, R2.2
/TMS: J4.5, U1.22 (TMS)
/VBEC: C6.2, J1.2, J2.2, J3.2, U2.3 (VI)
GND: C1.2, C2.2, C3.2, C4.2, C5.2, C6.1, C7.2, J1.3, J2.3, J3.1, J4.2, J4.10, U1.10 (GNDIO), U1.11 (GNDINT), U1.32 (GNDIO), U1.33 (IO1_33), U1.34 (IO1_34), U1.35 (IO1_35), U1.36 (IO1_36), U1.37 (IO1_37), U1.38 (IO1_38), U1.39 (IO1_39), U1.40 (IO1_40), U1.46 (GNDIO), U1.47 (IO1_47), U1.60 (GNDIO), U1.61 (IO2_61), U1.65 (GNDINT), U1.66 (IO2_66), U1.67 (IO2_67), U1.68 (IO2_68), U1.69 (IO2_69), U1.70 (IO2_70), U1.71 (IO2_71), U1.72 (IO2_72), U1.73 (IO2_73), U1.74 (IO2_74), U1.75 (IO2_75), U1.76 (IO2_76), U1.77 (IO2_77), U1.78 (IO2_78), U1.79 (GNDIO), U1.85 (IO2_85), U1.86 (IO2_86), U1.87 (IO2_87), U1.88 (IO2_88), U1.89 (IO2_89), U1.90 (IO2_90), U1.91 (IO2_91), U1.92 (IO2_92), U1.93 (GNDIO), U2.1 (GND), Y1.2 (GND)

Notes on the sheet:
C1..C4: 100n, one per side of U1, across an adjacent VCC/GND pair: 9/10, 31/32, 59/60, 79/80, within 2 mm. C5: 100n at Y1 Vdd. C6 / C7: at U2, 10u input (16 V) and 22u output. AMS1117 needs the output cap (22u tantalum, or 10u..22u ceramic) or it oscillates.

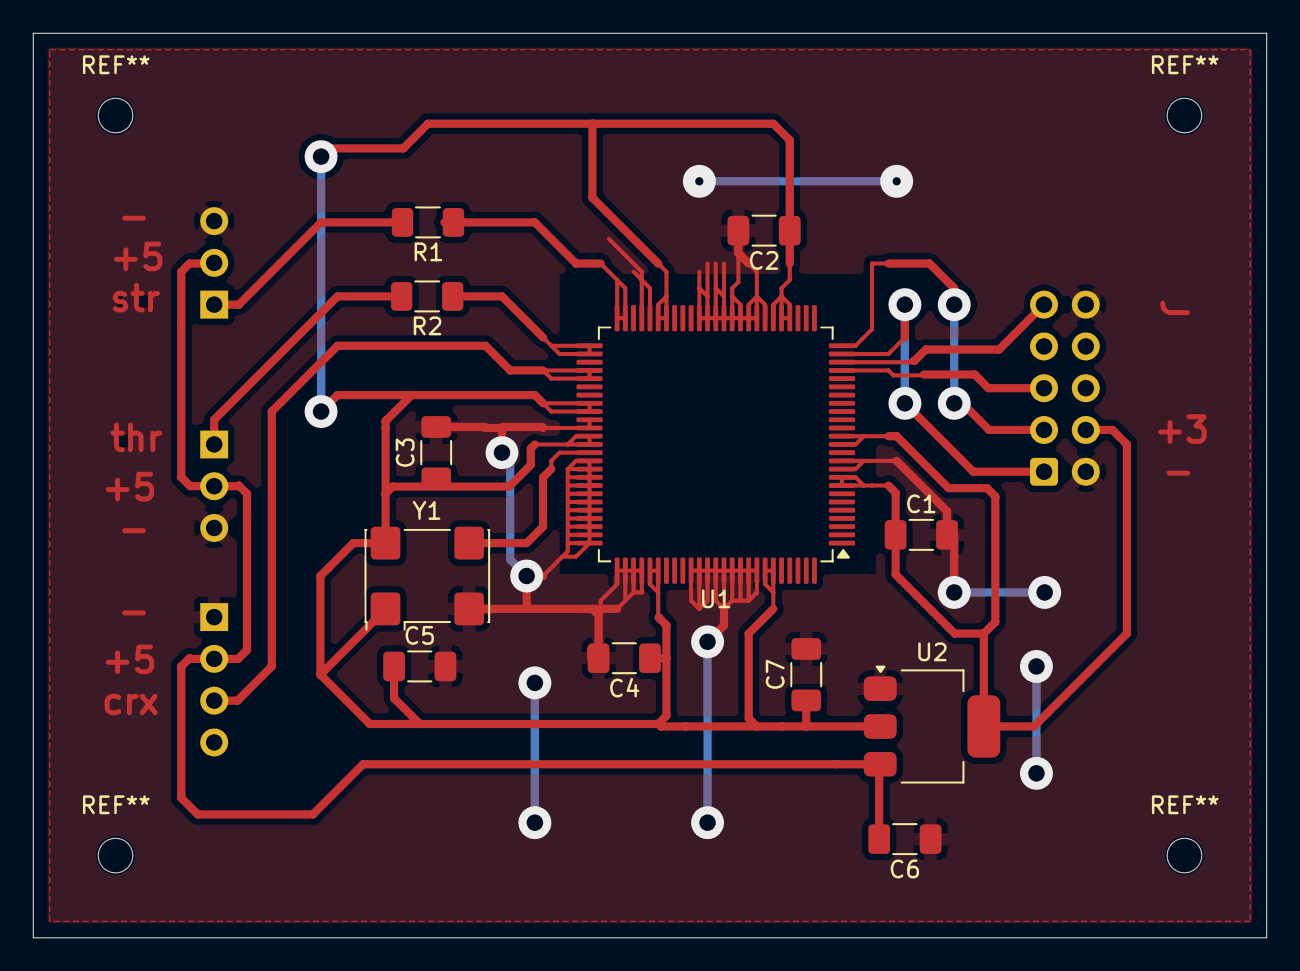
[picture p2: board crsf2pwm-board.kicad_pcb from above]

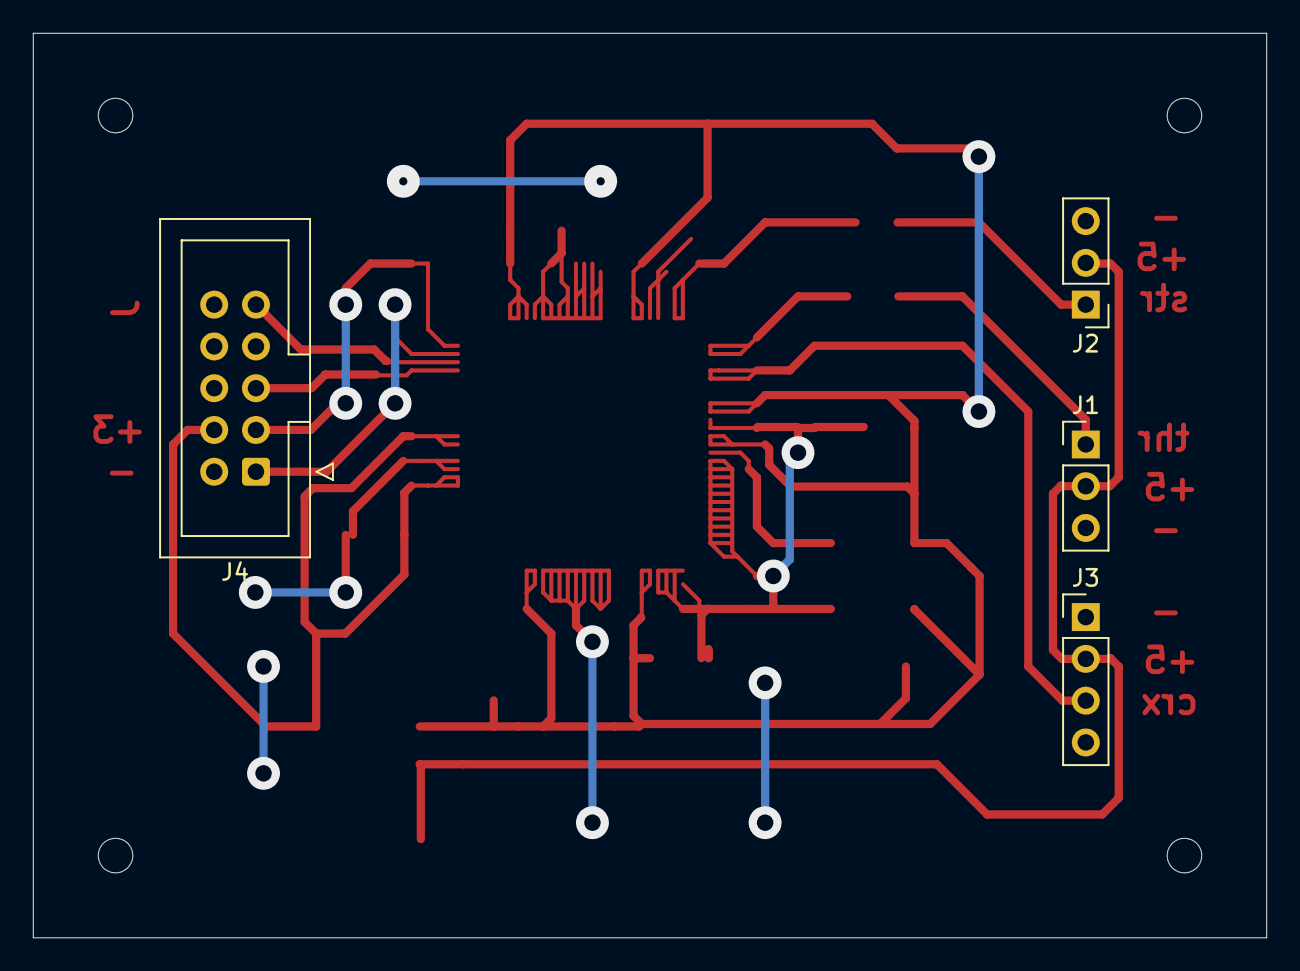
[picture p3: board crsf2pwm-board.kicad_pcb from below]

Board: 2 copper layers, 75.0 x 55.0 mm, 16 parts (4 on the bottom side), 13 nets.

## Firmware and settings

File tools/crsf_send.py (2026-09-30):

#!/usr/bin/env python3
"""Play an ELRS receiver: send CRSF RC frames from the PC over a serial port.

Uses the reference model in tb/model/crsf.py, so the bytes on the wire are
the same ones the testbenches were built on. The board's own USB-UART
bridge is the port when rx sits on M2 (see docs/pinout.md).

    tools/crsf_send.py                              centre both channels, 250 frames/s
    tools/crsf_send.py --steer 172 --throttle 1811  fixed values, CRSF units 172..1811
    tools/crsf_send.py --us --steer 1000 --throttle 2000
    tools/crsf_send.py --sweep 4                    steer sweeps end to end and back every 4 s
    tools/crsf_send.py --interactive                drive it from the keyboard, see below
    tools/crsf_send.py --bad-crc                    spoil every second frame: outputs must not react
    tools/crsf_send.py --duration 3                 stop after 3 s: watch the failsafe kick in
    tools/crsf_send.py --dry-run                    print the frames instead of sending them

Interactive keys (frames keep flowing while you type):
    a / d  or  left / right     steer  -/+ one step
    s / w  or  down / up        throttle -/+ one step
    A D S W                     ten steps
    c or space                  both to centre
    1 .. 9                      steer to -100 % .. +100 % in eight steps (5 is centre)
    q or Ctrl+C                 quit, which is a failsafe test

Ctrl+C stops it; that too is a failsafe test.
Needs pyserial: sudo apt install python3-serial   (or pip install pyserial)
"""

import argparse
import glob
import os
import pathlib
import select
import sys
import termios
import time
import tty

sys.path.insert(0, str(pathlib.Path(__file__).resolve().parents[1] / "tb" / "model"))
import crsf  # noqa: E402


def find_port():
    ports = sorted(glob.glob("/dev/ttyUSB*")) + sorted(glob.glob("/dev/ttyACM*"))
    if not ports:
        sys.exit("no /dev/ttyUSB* or /dev/ttyACM*: is the board's mini-USB plugged into this PC?")
    return ports[0]


def to_crsf(value, in_us):
    v = crsf.crsf_from_us(value) if in_us else int(value)
    if not 0 <= v <= 2047:
        sys.exit(f"channel value {value} out of range")
    return v


def clamp(v):
    return max(crsf.CH_MIN, min(crsf.CH_MAX, v))


def apply_key(key, steer, throttle, step):
    """One keystroke to new (steer, throttle, quit). Arrow keys arrive as ESC [ A/B/C/D."""
    big = 10 * step
    moves = {
        "a": (-step, 0), "d": (step, 0), "s": (0, -step), "w": (0, step),
        "A": (-big, 0), "D": (big, 0), "S": (0, -big), "W": (0, big),
        "\x1b[D": (-step, 0), "\x1b[C": (step, 0), "\x1b[B": (0, -step), "\x1b[A": (0, step),
    }
    if key in moves:
        ds, dt = moves[key]
        return clamp(steer + ds), clamp(throttle + dt), False
    if key in ("c", " "):
        return crsf.CH_MID, crsf.CH_MID, False
    if key in "123456789" and key:
        span = crsf.CH_MAX - crsf.CH_MIN
        return round(crsf.CH_MIN + span * (int(key) - 1) / 8), throttle, False
    if key in ("q", "\x03"):
        return steer, throttle, True
    return steer, throttle, False


def read_keys():
    """Keys waiting on stdin, possibly none. Read from the raw descriptor:
    Python's stdin buffer would swallow the tail of an escape sequence.
    An arrow key is ESC [ X and is returned as one key."""
    fd = sys.stdin.fileno()
    if not select.select([fd], [], [], 0)[0]:
        return []
    data = os.read(fd, 64)
    keys = []
    while data:
        if data[:1] == b"\x1b" and len(data) >= 3:
            keys.append(data[:3].decode(errors="replace"))
            data = data[3:]
        else:
            keys.append(data[:1].decode(errors="replace"))
            data = data[1:]
    return keys


def main():
    ap = argparse.ArgumentParser(description=__doc__, formatter_class=argparse.RawDescriptionHelpFormatter)
    ap.add_argument("--port", help="serial port, default: first /dev/ttyUSB*")
    ap.add_argument("--baud", type=int, default=420000)
    ap.add_argument("--rate", type=float, default=250, help="frames per second, default 250")
    ap.add_argument("--steer", type=float, default=992, help="channel 0")
    ap.add_argument("--throttle", type=float, default=992, help="channel 1")
    ap.add_argument("--us", action="store_true", help="values are microseconds, not CRSF units")
    ap.add_argument("--sweep", type=float, metavar="SECONDS", help="sweep steer end to end and back with this period")
    ap.add_argument("--interactive", "-i", action="store_true", help="change the values from the keyboard while running")
    ap.add_argument("--step", type=int, default=16, help="interactive step in CRSF units, default 16 (10 us)")
    ap.add_argument("--bad-crc", action="store_true", help="spoil the CRC of every second frame")
    ap.add_argument("--duration", type=float, help="seconds to run, default: until Ctrl+C")
    ap.add_argument("--dry-run", action="store_true", help="print frames as hex instead of sending")
    args = ap.parse_args()

    steer = to_crsf(args.steer, args.us)
    throttle = to_crsf(args.throttle, args.us)
    if args.interactive and args.sweep:
        sys.exit("--interactive and --sweep do not mix")
    if args.interactive and not sys.stdin.isatty():
        sys.exit("--interactive needs a terminal on stdin")

    if args.dry_run:
        port = None
        name = "stdout"
    else:
        try:
            import serial
        except ImportError:
            sys.exit("pyserial missing: sudo apt install python3-serial  (or pip install pyserial)")
        name = args.port or find_port()
        try:
            port = serial.Serial(name, args.baud, timeout=0)
        except serial.SerialException as e:
            sys.exit(f"cannot open {name}: {e}\n"
                     "permission denied usually means: sudo usermod -aG dialout $USER, then log in again")

    period = 1.0 / args.rate
    print(f"{name} @ {args.baud}: {args.rate:g} frames/s, steer {steer} ({crsf.us_from_crsf(steer):.1f} us), "
          f"throttle {throttle} ({crsf.us_from_crsf(throttle):.1f} us)"
          + (f", steer sweep {args.sweep:g} s" if args.sweep else "")
          + (", every second CRC spoiled" if args.bad_crc else ""))

    def status(values):
        return (f"steer {values[0]:4d} ({crsf.us_from_crsf(values[0]):6.1f} us)  "
                f"throttle {values[1]:4d} ({crsf.us_from_crsf(values[1]):6.1f} us)")

    channels = [crsf.CH_MID] * crsf.CH_COUNT
    sent = 0
    t0 = time.monotonic()
    next_t = t0
    last_report = t0
    tty_state = None
    if args.interactive:
        tty_state = termios.tcgetattr(sys.stdin)
        tty.setcbreak(sys.stdin.fileno())       # keys arrive at once, Ctrl+C still works
        print("a/d steer, w/s throttle, A/D/W/S x10, c centre, 1..9 steer presets, q quit")
    try:
        while True:
            now = time.monotonic()
            if args.duration is not None and now - t0 >= args.duration:
                break
            if args.interactive:
                quit_now = False
                keys = read_keys()
                for key in keys:
                    steer, throttle, quit_now = apply_key(key, steer, throttle, args.step)
                    if quit_now:
                        break
                if quit_now:
                    break
                if keys:
                    print(f"\r{status((steer, throttle))}   ", end="", flush=True)
            if args.sweep:
                # triangle between CH_MIN and CH_MAX
                phase = ((now - t0) / args.sweep) % 1.0
                tri = 2 * phase if phase < 0.5 else 2 * (1 - phase)
                channels[0] = round(crsf.CH_MIN + tri * (crsf.CH_MAX - crsf.CH_MIN))
            else:
                channels[0] = steer
            channels[1] = throttle

            frame = bytearray(crsf.rc_frame(channels))
            if args.bad_crc and sent % 2 == 1:
                frame[-1] ^= 0xFF

            if port is None:
                print(frame.hex(" "))
            else:
                port.write(frame)
            sent += 1

            if now - last_report >= 1.0 and port is not None and not args.interactive:
                print(f"\r{sent} frames, {status(channels)}   ", end="", flush=True)
                last_report = now

            next_t += period
            delay = next_t - time.monotonic()
            if delay > 0:
                time.sleep(delay)
            else:
                next_t = time.monotonic()      # fell behind, do not burst
    except KeyboardInterrupt:
        pass
    finally:
        if tty_state is not None:
            termios.tcsetattr(sys.stdin, termios.TCSADRAIN, tty_state)
        if port is not None:
            port.close()
        print(f"\n{sent} frames sent, stopped: the board should fail safe in about 0.5 s")


if __name__ == "__main__":
    main()

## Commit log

2026-09-28 PWM support was added
2026-09-29 Testbench was added for pwm
2026-09-30 Pinout fix for own board. Docs update + aux utils were added
2026-09-30 Usage usb/uart converter was added for cyclone4 board
2026-09-30 Script to simulate crsf from PC was added. CI job fixed
    [crsf_send.py]
2026-10-01 Sketch of scheme was added
    [crsf2pwm-board.kicad_pcb, crsf2pwm-board.kicad_sch]
2026-10-02 Initial pcb was created
    [crsf2pwm-board.kicad_pcb, crsf2pwm-board.kicad_sch]
2026-10-02 Redesigned. Now checks ok
    [crsf2pwm-board.kicad_pcb, crsf2pwm-board.kicad_sch]
2026-10-03 jumpers were added to improve traces
    [crsf2pwm-board.kicad_pcb, crsf2pwm-board.kicad_sch]
2026-10-03 Case sizes for resistors/capasitors and vias were increased
    [crsf2pwm-board.kicad_pcb, crsf2pwm-board.kicad_sch]
2026-10-03 Track width was increased
    [crsf2pwm-board.kicad_pcb]
2026-10-03 Clearance/width of tracks was increased to 0.5mm for easy handsoldering
    [crsf2pwm-board.kicad_pcb]
2026-10-03 extra copper zone under u1 was removed
    [crsf2pwm-board.kicad_pcb]
2026-10-05 Minor captions were added
    [crsf2pwm-board.kicad_pcb]
2026-10-05 Text was knocked out
    [crsf2pwm-board.kicad_pcb]
2026-10-05 Minor page settings update
    [crsf2pwm-board.kicad_pcb]
2026-10-06 Kicad actions were added
2026-10-07 Signal pins were gaped to allow easy manual soldering
    [crsf2pwm-board.kicad_pcb, crsf2pwm-board.kicad_sch]
2026-10-08 Most unused pins were merged for easy soldering
    [crsf2pwm-board.kicad_pcb, crsf2pwm-board.kicad_sch]
2026-10-08 Some tracks were widen
    [crsf2pwm-board.kicad_pcb]
2026-10-08 Ground clearance was increased
    [crsf2pwm-board.kicad_pcb]
2026-10-13 Quartz generator was replaces for max2 board. Bom generation was added
2026-10-29 ERC bidirectional pin errors fix
